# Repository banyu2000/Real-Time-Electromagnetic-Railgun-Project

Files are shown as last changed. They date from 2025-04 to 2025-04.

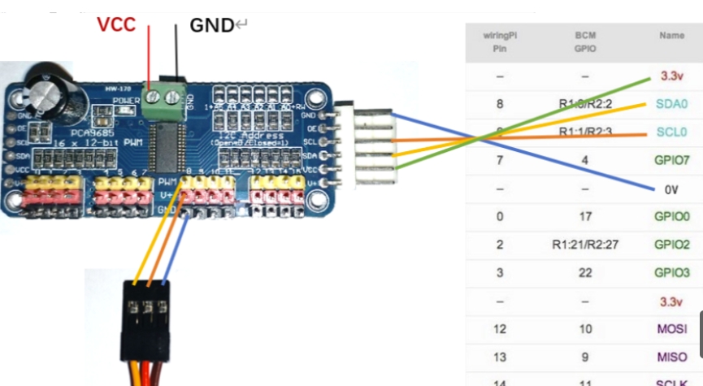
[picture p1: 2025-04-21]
docs/PCA9685_CONNECT_GUILDENCE.jpg

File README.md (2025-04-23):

# 🕊️ Real-Time Electromagnetic Railgun - Agricultural Deterrent System (Prototype)

This project is a real-time embedded system that detects visual targets (e.g. birds), calculates servo aiming, and triggers an actuator (electromagnetic railgun in demo).  
It is designed as a **proof-of-concept for smart deterrent systems**, particularly in agricultural environments.

## 🧩 System Overview

This project is organized into five tightly integrated subsystems, each responsible for a key piece of the “detect → aim → fire” feedback loop:

1. **Vision Module**  
   - Captures live video frames via libcamera  
   - Converts frames to OpenCV `cv::Mat` for processing  
   - Applies HSV color filtering + morphological operations to detect blue cylindrical targets  
   - Outputs the target’s centroid coordinates and contour bounding box

2. **Servo Control Module**  
   - Uses a PCA9685 I²C PWM driver to command two servos (horizontal & vertical)  
   - Converts detected error offsets (px) into angular adjustments (±0.5° precision)  
   - Supports two modes:  
     - **Manual Sweep**: continuous back‑and‑forth scan  
     - **Tracking**: lock onto detected target and hold position

3. **Launcher (Electromagnetic Barrel)**  
   - **Step‑up Circuit**: 3× 18650 cells → boost converter (15 µH coil + diode) → 1000 µF storage capacitor  
   - **Discharge Path**: relay (or N‑MOSFET) closes to dump capacitor into copper coil wound around a plastic barrel  
   - **Projectile**: small steel ball seated in the barrel’s center is launched by the magnetic pulse

4. **Callback & Multithreading Framework**  
   - **LibCam2OpenCV** runs camera capture in its own thread, invokes `hasFrame()` slot in the GUI thread  
   - **ServoThread** (inside `Window`) processes angle updates in a worker thread to keep UI responsive  
   - **SequenceController** runs charge–pause–discharge relay sequence on a detached thread when “lock” conditions are met  
   - Thread‐safe coordination via `std::atomic<bool>` and `std::function` callbacks

5. **Qt GUI Interface**  
   - **Live View**: displays current camera frame with overlaid detection box & center point  
   - **Controls**:  
     - **Start Sweep** button toggles manual scanning mode  
     - **Track Mode** button enables automatic target‐lock behavior  
   - **Indicators**: shows real‐time servo angles, relay status, and system health  
   - Built with Qt Widgets and optionally uses Qwt for custom gauges (e.g. QwtThermo)

---

All five subsystems are orchestrated by the main application, which:  
- Initializes hardware (I²C, GPIO, camera)  
- Launches the Qt event loop and camera capture  
- Monitors for SIGINT to gracefully shut down threads and reset actuators  
- Provides a modular codebase in `src/`, easy to extend with new sensors, actuators, or network interfaces  

---

##  Project Background & Motivation

In agriculture, birds cause significant damage to crops by eating seeds and fruits. Traditional scarecrow systems are passive, and manual patrols are time-consuming and ineffective.

Our project aims to address this problem by building an **automated deterrent platform**, capable of:
- Detecting moving visual targets using a camera
- Aiming servos to lock onto targets in real time
- Triggering an actuator (e.g., railgun / speaker / LED blaster) to deter targets

Although the current system uses a railgun for demonstration, the design is modular and can be adapted for:
-  Smart farm protection
-  Perimeter defense simulation
-  Embedded systems education

---

##  Demo Preview

>  Target detection + servo movement + firing sequence

Demo mp4

>  Real-time detection output

Detection Example

---

##  Tests Preview

Below are snapshots from our various unit- and integration‑tests, all located under the `tests/` directory:

| Test Module | Description | Preview |
|---|---|---|
| **Servo Test** | `tests/test1_servo/` sweep demo | Servo Test |
| **GUI Test** | `tests/test2_UI/` UI functionality | GUI Test |
| **IO Control Test** | `tests/test3_io_control/` relay logic | IO Test |
| **ServoCam Test** | `tests/test4_ServoCam/` full pipeline | ServoCam |
| **Camera Test** | `tests/test5_camera/` framerate check | Camera |

---

##  System Overview

-  **Vision Module**: HSV-based blue target detection (OpenCV)
-  **Servo Control**: Dual-axis aiming with PCA9685, ±0.5° accuracy
-  **Launcher**: Electromagnetic railgun with capacitor boost & relay control
-  **Callback & Multithreading**: Threads handle image capture, control logic, and GPIO actions
-  **Qt GUI**: Live video stream, system status, and manual controls

 Architecture diagram: [`docs/system_architecture.md`](docs/system_architecture.md)

---

##  How to Run

###  Build & Run Servo Test

```bash
mkdir build && cd build
cmake ..
make
sudo ./servo_test

``` 

---

###  Test Output 

- Servo sweeps automatically from 0° to 180°

- Vision module detects blue objects and overlays bounding boxes

- Qt UI displays live feedback and control panel

Full demo video : media/demo.mp4

---

###  Documentation (`/docs`)

| File | Description |
|---|---|
| [`project_log.md`](docs/project_log.md) | Project development timeline & milestones |
| [`system_architecture.md`](docs/system_architecture.md) | Hardware/software architecture |
| [`end_of_life.md`](docs/end_of_life.md) | Reflection, limitations & future improvements |
| [`credits.md`](docs/credits.md) | Team member responsibilities |

---

###  Repository Structure

- `build/` — Build output directory (excluded by `.gitignore`)
- `docs/` — Project documentation
  - `project_log.md` — Development timeline and milestones
  - `system_architecture.md` — Architecture and design overview
  - `end_of_life.md` — Final reflection and improvement analysis
  - `credits.md` — Team member responsibilities
- `media/` — Demo images, GIFs, and video assets
  - `demo.gif`, `vision_output.png`, `system_diagram.png`
- `src/` — Main source code (servo, vision, callback, GUI, etc.)
- `tests/` — Unit tests and module demos (e.g., `servo_test`)
- `.gitignore` — Git exclusion rules (build folders, binaries, temp files)
- `CMakeLists.txt` — CMake build configuration
- `LICENSE` — MIT open-source license
- `README.md` — Project overview, usage, and documentation links

---

###  Contributors

| Name | ID | Role |
|---|---|---|
| **Baichuan Shi**  | 2982811  | Servo control, GitHub management |
| **Xiang Chen** | 3052701  | IO logic, relay control |
| **Yu Ban** | 2931341  | Vision detection (OpenCV) |
| **Kunjin Chen** | 2981978  | Callback mechanism, threading |
| **Zhongkai Zhang**| 2969533  | Qt GUI development |
---

## 🎥 Social Media

Check out our project demo on TikTok:  
[Real‑Time Electromagnetic Railgun Demo](https://www.tiktok.com/@user99861255807300?_t=ZN-8ve2aKE0Rx0&_r=1)

---

##  Third‑Party Libraries

Project Name: libcamera2opencv  
Author: Bernd Porr  
Link: https://github.com/berndporr/libcamera2opencv  
License: GPL-2.0 License  

---

### License

This project is licensed under the MIT License. See LICENSE for details.

---

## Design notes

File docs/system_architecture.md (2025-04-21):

# System Architecture

This document describes the overall architecture of the Real-Time Electromagnetic Railgun System, including its functional modules, data/control flows, and hardware-software integration.

---

##  System Overview

The system consists of five tightly integrated subsystems:

| Subsystem | Description |
|---|---|
| **Vision Module** | Detects and tracks targets using a camera and OpenCV-based neural network |
| **Servo Control** | Adjusts the aiming angle based on target coordinates |
| **Firing Circuit** | Charges capacitors and releases high-current pulses via relay control |
| **I/O Control** | Reads and writes GPIO for relay switching and power status feedback |
| **UI Interface** | Provides real-time video feed and system status via a Qt GUI |

---

##  Module Interaction Flow

```plaintext
[Camera Feed] ─▶ [Vision Recognition] ─▶ [Callback Dispatch] ─▶ [Servo Control]
                                                     │
                                                     ▼
                                               [IO & Relay Trigger]
                                                     │
                                        [Capacitor Discharge (Fire)]
```

---
All components are coordinated via real-time callbacks and thread-safe communication queues.
---
## Hardware Block Diagram
## 🔌 Hardware Block Diagram

- **Power Supply**: 3× 18650 Li‑ion batteries in series (~12 V nominal)  
- **Step‑up Circuit**: Boost converter with 15 µH inductor + flyback diode  
  _(or use a commercial DC–DC boost module rated for ≥20 V, ≥5 A output)_  
- **Control Switches**:  
  - Prototype: manual toggles SW1/SW2  
  - Final: 2‑channel relay module driven by Raspberry Pi GPIO  
- **Capacitor**: 1000 µF electrolytic for energy storage before discharge  
- **Discharge Switch**: N‑MOSFET or relay to route discharge current into coil  
- **Barrel (Launcher Coil)**:  
  - Copper coil wound around a non‑conductive plastic tube  
  - Steel ball projectile seated in the tube’s center  
  - When discharged, the coil’s magnetic pulse propels the ball forward  

---

## Software Threading & Signal Handling
Thread / Task | Description
Vision Thread | Processes camera frames, outputs target positions
Callback Dispatcher | Routes vision output to servo + IO threads
Servo Thread | Converts target position to angle; sends to PCA9685
I/O Thread | Reads safety sensors, controls relay pins
UI Thread | Displays video stream, status indicators, user buttons
---

## Communication Interfaces
²C: Used for servo control via PCA9685 module

GPIO: Raspberry Pi controls relay signals (charge/discharge trigger)

Internal Queues: Thread-safe std::queue/Qt signals for module coordination

USB Camera or PiCamera: Frame source for real-time processing
---

## Notes on Electrical Design

Old Design (see schematic):

Uses MOSFET (VS-70TPS12PBF) for switching

Boost inductor + diode creates charging loop

Two push-button switches (SW1/SW2) manually control flow

New Design:

Replaces manual switches and MOSFET with relay modules

GPIO triggers allow safe, programmable operation

Enhanced with software interlock logic

---

## Summary

The system ensures:

Modular and testable architecture

Real-time control loop (detection → aiming → firing)

Safe hardware operation via callback and interlock logic

Clear power and control signal paths for easy debugging and reproduction

---

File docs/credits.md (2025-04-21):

# 👥 Project Team & Responsibilities

This document outlines the role and responsibilities of each team member in the **Real-Time Electromagnetic Railgun Project**, as well as the technical scope they covered.

---

## 🧑‍💻 Team Members & Detailed Contributions

### **🧭 Xiang Chen (3052701) – I/O Control & Switching Logic**

#### 🔹 Background
Develop I/O port drivers and control logic in `feature/io-control` to ensure stable hardware signal transmission.

#### 🔹 Responsibilities
- GPIO initialization via Linux subsystem
- Designed full port mapping table and pull-up/down setup
- Developed switch state machine (standby → ready → launch → reset)
- Implemented interlock + fault detection (short-circuit, voltage anomalies)
- Integrated I/O with servo and callback modules via thread-safe queues

#### ✅ Acceptance Criteria
- Signal delay ≤ 100μs, 100% I/O read/write accuracy
- Emergency stop triggered in ≤ 50ms
- Fully documented driver code

---

### **⚙️ Baichuan Shi (2982811) – Servo Control Module**

#### 🔹 Background
Servo control is key for adjusting the firing angle in the railgun. A stable, precise control system is required.

#### 🔹 Responsibilities
- Designed PID-based angle adjustment algorithm (±0.5° tolerance)
- Wrote custom servo driver via PCA9685
- Monitored real-time angle, speed, and errors
- Integrated control with vision and UI
- Conducted performance testing

#### ✅ Acceptance Criteria
- Angle error ≤ ±0.5°
- Fast target response, stable output
- Robust driver and feedback loop

---

### **🧠 Kunjin Chen (2981978) – Callback Coordination & Threading Architecture**

#### 🔹 Background
Ensure real-time concurrent processing between vision, servo, and I/O modules via efficient callback architecture.

#### 🔹 Responsibilities
- Designed C++ virtual interface / Qt signal-slot based callbacks
- Implemented asynchronous dispatching + exception handling
- Built multithreaded architecture using C++11 / QThreads
- Optimized for performance (e.g., lock-free queues, SIMD)
- Ensured memory safety with smart pointers

#### ✅ Acceptance Criteria
- Vision callback delay ≤ 100ms, servo delay ≤ 50ms
- CPU load ≤ 80% under stress
- ≥ 95% error handling coverage, ≤ 2s recovery time

---

### **📷 Yu Ban (2931341) – Vision Recognition**

#### 🔹 Background
Enhance the accuracy and efficiency of target detection in the `feature/vision-recognition` branch.

#### 🔹 Responsibilities
- Integrated and optimized YOLOv8-light for real-time detection
- Enhanced image pre-processing (noise filtering, white balance)
- Implemented DeepSORT-based multi-target tracking
- Packaged module as `libvision.so`, created API docs
- Achieved 80%+ unit test coverage

#### ✅ Acceptance Criteria
- mAP@0.5 ≥ 85%, inference time/frame ≤ 150ms
- Modular, documented, and testable code

---

### **🖥 Zhongkai Zhang (2969533) – Qt GUI Development**

#### 🔹 Background
Integrate live video and GPIO control into a smooth, functional Qt interface.

#### 🔹 Responsibilities
- Designed UI layout (video, controls, status monitor)
- Connected live PiCamera feed via OpenCV
- Implemented resolution settings, start/stop threading
- Built GPIO status widgets (e.g., QLEDWidget, error log)
- Created reusable Qt components with Doxygen docs

#### ✅ Acceptance Criteria
- Stream delay ≤ 500ms, UI buttons functional
- GPIO control latency ≤ 200ms
- Code passed PR review and Qt guidelines

---

## 🤝 Teamwork and Integration

- Followed GitFlow model with `feature/`, `develop`, and `release` branches
- Used GitHub Issues to manage tasks and document bugs
- Integrated via callback pipelines across vision ↔ servo ↔ IO
- Each member contributed test cases and documentation

---

## 🙏 Acknowledgements

This project was developed as part of **ENG5220: Real-Time Embedded Systems** at the University of Glasgow.

Special thanks to:

- **Prof. Bernd Porr** – for guidance on embedded control systems
- **Dr. Chongfeng Wei** – for support on hardware interfacing
- **All TAs and lab staff** – for test environment and debugging help

---

## 📜 License

Distributed under the [MIT License](../LICENSE).  
We welcome forks, feedback, and future contributions.

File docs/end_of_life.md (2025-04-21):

#  End of Life Analysis & Future Prospects

This document summarizes the current limitations, potential improvements, and reusable value of the Real-Time Electromagnetic Railgun Project. The system demonstrates a complete real-time feedback loop from vision-based target detection to servo-based aiming and electromagnetic firing. It is designed not only as a technical showcase, but also as a prototype to solve real-world control problems in security, automation, and education.

---

##  Real-Life Motivation

Many real-life scenarios such as smart defense systems, interactive shooting ranges, or embedded system education platforms require real-time decision-making based on visual input. Our system addresses this by combining:

- Visual detection of objects (color-based)
- Real-time servo aiming control
- Software-controlled electromagnetic actuation
- Integrated feedback via GUI

Applications include:

-  Smart deterrent systems (e.g. bird control in agriculture)
-  Interactive shooting/targeting training
-  Teaching platform for embedded systems and robotics

---

## Achievements Summary

- Servo angle control achieved with ±0.5° precision using PCA9685
- Real-time yellow object detection using OpenCV (HSV filtering + morphological operations)
- Detection latency under 50ms per frame (800×600 on Raspberry Pi 4)
- Multi-threaded callback architecture linking vision, control, and IO
- Integrated Qt GUI showing live video, detection bounding boxes, and system states
- Stable electromagnetic firing with software-defined state transitions

---

##  Known Limitations

| Category | Description |
|---|---|
| **Budget & Time** | Limited by academic constraints: low-cost camera impacts image clarity and detection robustness |
| **Hardware** | - Capacitor energy insufficient for rapid repeat fire<br>- Boost charging is slow<br>- Relay-based switching has delay and limited lifespan |
| **Mechanical Design** | No auto-reload mechanism; no environmental casing or protection |
| **Safety & Compliance** | System lacks industrial-grade protection (no watchdog, thermal cutoff, voltage monitoring) |

---

##  Future Improvements

- Replace relays with fast-switching IGBTs or power MOSFETs
- Use larger capacitors for better launch power and faster recharge
- Add auto-reloading mechanics and a secure protective casing
- Integrate thermal sensors, kill switches, and soft-fail mechanisms
- Upgrade to a better camera module or use Jetson Nano platform for high-speed image processing
- Modularize vision-to-servo link using lightweight messaging or ROS-lite interface

---

##  Reusability & Application Potential

This project can be repurposed or extended in multiple directions:

- **Agricultural automation**: Auto-targeting deterrents for wildlife control
- **Educational platform**: Demonstrates perception → decision → act loop for embedded systems teaching
- **Defense simulation**: Low-cost turret prototype for vision-guided robotics research

The modular nature and clean threading model make it suitable for forking and repurposing in future course projects or product prototypes.

---

##  Lessons Learned

- Git structure and branch discipline must be established early to avoid chaos later
- Physical circuits behave differently from simulation; real testing is essential at every stage
- Underestimating servo stall current and MOSFET load handling led to burnout and iteration delays
- Callback coordination and multithread safety should be prototyped early, not post-integration
- Continuous integration testing is more effective than final-phase testing rush

---

##  Conclusion

This project successfully demonstrates a reproducible real-time closed-loop embedded system capable of fulfilling real-world perception-to-action tasks. It also lays the foundation for further improvements in precision, safety, and intelligent control in small-scale robotic systems.

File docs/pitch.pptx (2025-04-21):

## Real Time Electromagnetic Railgun Project

01

Basic Functionality:

Automatically calculates launch velocity based on input angle and distance.

02

Advanced Features:

Utilizes visual recognition and laser ranging to determine barrel angle and target distance for automated projectile launching.

## Model demonstration

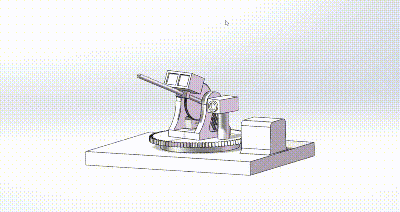
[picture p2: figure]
电磁炮[00h00m02s-00h00m19s]

System Components

Raspberry Pi Control System
Information Collection System
Human-Machine Interaction
System
Electromagnetic Railgun
System

Hardware Components

Raspberry Pi
Electromagnetic coil
High voltage capacitor bank
Boost module
Servo Motor
Laser Sensor
Vision Sensor
Power system (power supply)

banyu2000/Real-Time-Electromagnetic-Railgun-Project (https://github.com/banyu2000/Real-Time-Electromagnetic-Railgun-Project)

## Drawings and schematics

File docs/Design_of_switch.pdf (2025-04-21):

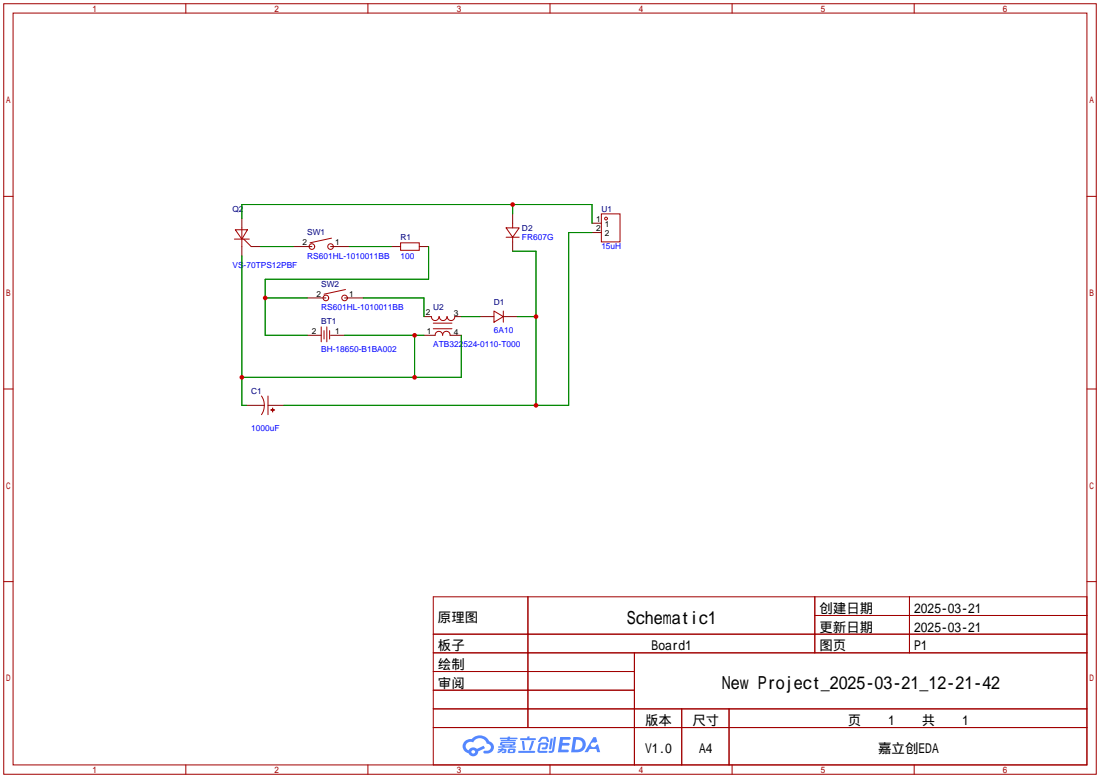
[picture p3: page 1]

原理图 | Schematic1 | 创建日期 | 2025-03-21

更新日期 | 2025-03-21

板子 | Board1 | 图页 | P1
绘制 | | New Project_2025-03-21_12-21-42
审阅

V1.0 | A4 | 嘉立创EDA

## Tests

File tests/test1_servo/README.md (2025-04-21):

# 🧪 Servo Unit Test – PCA9685 PWM Driver

This test verifies the functionality of the servo control system using a PCA9685 PWM driver over I2C on Raspberry Pi 5.

---

##  Purpose

This unit test:
- Initializes the PCA9685 device via I2C
- Continuously sweeps two servo motors across their full angular range (0° to 180°)
- Uses graceful termination (SIGINT) to reset both servos to 90° on exit

---

##  Files in this directory

| File | Description |
|---|---|
| `main.cpp` | Test program for dual-axis servo sweep |
| `PCA9685.cpp` | Implementation of the I2C PWM driver |
| `PCA9685.h` | Header file for PCA9685 class |
| `CMakeLists.txt` | CMake configuration for building the test |

---

##  Build Instructions

### Requirements:
- Raspberry Pi with I2C enabled (`/dev/i2c-1`)
- 2 servo motors connected to PCA9685 (channels 0 and 1)
- CMake & C++17 compiler (e.g., `g++`)

### Compile with CMake:
```bash
mkdir -p build && cd build
cmake ..
make
``` 
---

The output executable will be: servo_test

---

 ### Run the Test
```bash
sudo ./servo_test
``` 
The horizontal servo (channel 0) will sweep from 0° to 180°

The vertical servo (channel 1) will sweep from 180° to 0°

Press Ctrl+C to stop – the servos will return to 90° automatically

---

### Example console output:
```yaml
Horizontal: 0°   Vertical: 180°
Horizontal: 10°  Vertical: 170°
...
Program terminated. Servos reset.
```

---

### Test Outcome Criteria

Metric	Condition
I2C connection|	No runtime exception
Angle movement|	Smooth servo sweep observed
Exit handling|	Servos return to neutral

---

### Notes：

PCA9685 default I2C address: 0x40

If you're not using /dev/i2c-1, change I2C_DEV in PCA9685.h

Use a dedicated power supply for servos if they draw significant current

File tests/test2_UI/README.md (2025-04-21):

# 🧪 Qt UI Integration Test – Camera + GPIO Interface

This test verifies the functionality of the user interface using Qt5 on Raspberry Pi, with real-time camera integration and GPIO control layout preparation.

---

## ✅ Purpose

This integration update:
- Displays live camera feed from Raspberry Pi (libcamera or OpenCV)
- Constructs the main UI layout using Qt5
- Adds two interactive buttons at the bottom of the interface:
  - `Auto Shoot`
  - `Track Shoot`
- These buttons are now visible and placed for future GPIO interaction

---

## 📁 Files in this directory

| File | Description |
|---|---|
| `main.cpp` | Entry point of the Qt application |
| `window.cpp` | Implementation of the UI, image display, and layout |
| `window.h` | Header for the main Window class |
| `CMakeLists.txt` | CMake configuration for building the GUI |

---

## 🔧 Build Instructions

### Requirements:
- Raspberry Pi with Qt5 and OpenCV installed
- Camera module (e.g., Raspberry Pi Camera v1.3) connected via CSI
- CMake, g++, and pkg-config available

### Compile with CMake:
```bash
mkdir -p build && cd build
cmake ..
make

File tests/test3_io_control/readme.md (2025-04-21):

#  Relay Switch Unit Test – GPIO Control with libgpiod

This unit test verifies GPIO-based relay switching using the `libgpiod` C++ library on Raspberry Pi 5.  
It simulates a charge–discharge sequence using two GPIO pins controlling physical switches.

---

##  Purpose

This test program:
- Initializes two GPIO output lines (GPIO27 and GPIO22)
- Responds to user input (`on`) to activate a switch sequence
- Gracefully shuts down and resets the switches on `Ctrl+C` or `exit` command

---

##  Files in This Directory

| File | Description |
|---|---|
| `main.cpp` | Main test program with GPIO sequence control  |
| `CMakeLists.txt` | Add if using CMake to build the program |

---

##  Build Instructions

### Prerequisites:
- Raspberry Pi 5 with GPIO support
- Relay or LED circuit connected to GPIO27 and GPIO22
- `libgpiod` installed:
  ```bash
  sudo apt install libgpiod-dev
  ```
  
---

## Compile Manually:
```bash
mkdir build && cd build
cmake ..
make
```
---

## Run the Test
```bash
 ./relay_test
```
---

### You will see a prompt like:
```scss
System ready. GPIO27(switch1), GPIO22(switch2)
> 
```
Type on to trigger the switch sequence:

switch1 turns ON for 2s → OFF

0.5s pause

switch2 turns ON for 1s → OFF

Type exit or press Ctrl+C to quit. All GPIOs will be turned off cleanly.

---

## Test Outcome Criteria

Metric | Condition
GPIO Initialization | No runtime exception or access error
Sequence Logic | Relays trigger in correct timing
Signal Handling | Exits cleanly on Ctrl+C, resets pins

---

### Notes

-Uses GPIO27 and GPIO22 by default. Change in SequenceController if needed.

-Requires libgpiod and root privileges (sudo) to access GPIO.

-You can connect relays or LEDs for visual confirmation.

---

## Example Output
```YAML
System ready. GPIO27(switch1), GPIO22(switch2)
> on
Switch ON
Switch OFF
Switch ON
Switch OFF
> exit
System shutdown
```
---

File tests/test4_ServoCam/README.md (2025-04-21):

# ServoCam Test

A real-time object detection and tracking system that integrates **libcamera**, **OpenCV**, and a **PCA9685** PWM servo driver, featuring a Qt-based GUI with auto-scan and tracking modes.

---

## Features

- **Camera Capture**: High-performance image acquisition using **libcamera** and **OpenCV**
- **Object Detection**: Yellow cylindrical can detection via HSV color filtering and contour analysis
- **Servo Control**: Pan-tilt control of two servos through PCA9685 over I²C
- **Tracking Mode**: Real-time target centering by adjusting servo angles based on object position
- **Scan Mode**: Automatic sweeping movement when no target is detected
- **Multithreading**: Dedicated `ServoThread` for servo operations; main thread handles image processing and UI
- **Callback Mechanism**: `Libcam2OpenCV` invokes a callback for each captured frame
- **GUI Interface**: Built with Qt5 Widgets and Qwt thermometer widget to display video feed and system status

---

## Repository Structure

```
├── CMakeLists.txt       # Build configuration
├── main.cpp             # Application entry point, initializes Qt application and main window
├── window.h/.cpp        # Qt window: UI setup, image updates, detection logic, and servo control
├── libcam2opencv.h/.cpp # Wrapper for libcamera to deliver OpenCV Mat frames via callback
├── PCA9685.h/.cpp       # PCA9685 I²C driver implementation and angle-to-PWM mapping
└── README.md            # Project documentation (this file)
```

---

## Hardware Requirements

- A libcamera-supported camera module (e.g., Raspberry Pi Camera)
- PCA9685 PWM driver connected via I²C
- Two standard analog servos connected to PCA9685 channels 0 (pan) and 1 (tilt)
- Linux-based embedded platform (e.g., Raspberry Pi) with I²C enabled (`/dev/i2c-1`)

---

## Software Dependencies

- **C++17**
- **libcamera**
- **OpenCV**
- **Qt5 Widgets**
- **Qwt**
- **pthreads**
- **pkg-config**

---

## Build and Run Instructions

1. **Install Dependencies** (Debian/Ubuntu):
   ```bash
   sudo apt update
   sudo apt install -y libopencv-dev libqt5widgets5 libqt5core5 pkg-config libqwt-qt5-dev libcamera-dev
   ```

2. **Build the Project**:
   ```bash
   mkdir -p build && cd build
   cmake ..
   make -j$(nproc)
   ```

3. **Run the Application**:
   ```bash
   sudo ./ServoCam
   ```
   (*sudo* may be required for I²C access)

---

## Usage

- **Start Servo**: Click to begin or stop automatic scanning.
- **Track Mode**: Toggle to enable or disable object tracking. In tracking mode, the servos will follow the detected can; if no can is found, the system reverts to scan mode.

---

## Module Overview

### libcam2opencv

- Initializes and configures the camera via **libcamera**.
- Maps camera buffers into **OpenCV** `cv::Mat` frames.
- Emits each frame through a virtual callback `hasFrame(const cv::Mat&, const libcamera::ControlList&)`.
- Allows setting capture parameters: resolution, framerate, brightness, contrast.

### PCA9685

- Opens `/dev/i2c-1` and sets up the PWM driver at 50 Hz.
- Provides `setAngle(uint8_t channel, float angle)` to convert angles (0–180°) into PWM pulse widths.
- Handles raw register writes and frequency adjustment.

### Window (Qt GUI)

- Builds the user interface with Qt5 Widgets and a Qwt thermometer for status display.
- Receives each frame in `updateImage()`, applies detection, draws overlays, and updates the video display.
- Contains `ServoThread` for continuous scanning movements and invokes servo adjustments in tracking mode.

---

## Customization

- Modify HSV threshold values in `detectCans()` to detect objects of different colors.
- Adjust pan/tilt step sizes for faster or smoother tracking responses.
- Replace the HSV-based detector with machine learning models (e.g., YOLO, TensorFlow) for advanced object recognition.

---

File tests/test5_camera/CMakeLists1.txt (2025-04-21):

cmake_minimum_required(VERSION 3.6)

if(NOT CMAKE_BUILD_TYPE AND NOT CMAKE_CONFIGURATION_TYPES)
  set(CMAKE_BUILD_TYPE "RelWithDebInfo")
endif()

project(CamViewer
	DESCRIPTION "Example QT application which displays the camera image"
	LANGUAGES CXX)

set (CMAKE_CXX_STANDARD 17)

set (CMAKE_CXX_FLAGS "-Wall -Winvalid-pch -Wnon-virtual-dtor -Wextra -Wno-unused-parameter")

find_package(PkgConfig)

find_package(OpenCV REQUIRED)

find_package(Qt5 COMPONENTS Widgets REQUIRED)

set(CMAKE_AUTOMOC ON)
set(CMAKE_AUTORCC ON)
set(CMAKE_AUTOUIC ON)

pkg_check_modules(LIBCAMERA REQUIRED IMPORTED_TARGET libcamera)
message(STATUS "libcamera library found:")
message(STATUS "    version: ${LIBCAMERA_VERSION}")
message(STATUS "    libraries: ${LIBCAMERA_LINK_LIBRARIES}")
message(STATUS "    include path: ${LIBCAMERA_INCLUDE_DIRS}")

message(STATUS "opencv:")
message(STATUS "    version: ${OpenCV_VERSION}")
message(STATUS "    include path: ${OpenCV_INCLUDE_DIRS}")

include_directories(${CMAKE_SOURCE_DIR} ${LIBCAMERA_INCLUDE_DIRS} ${OPENCV_INCLUDE_DIRS})
include(GNUInstallDirs)

add_executable(qtviewer
  window.cpp
  main1.cpp
)

target_link_libraries(qtviewer PkgConfig::LIBCAMERA)
target_link_libraries(qtviewer Qt5::Widgets)
target_link_libraries(qtviewer qwt-qt5)
target_link_libraries(qtviewer ${OpenCV_LIBS})
target_link_libraries(qtviewer cam2opencv)

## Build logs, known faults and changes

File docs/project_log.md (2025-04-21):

# 📅 Project Development Log

This document records key milestones and development progress of the Real-Time Electromagnetic Railgun Project.

---

##  Log Format

| Date | Task / Milestone | Description / Outcome | Responsible |
|---|---|---|---|

| **Feb 5**  |  Pitch Day                                      | Initial team formation and concept pitching                | All members |
| **Feb 26** |  Hardware Prepared                              | All critical components (servo, PCA9685, camera, relays) purchased | All members |
| **Mar 5**  |  Soldering Manual Switch Circuit                | Physical switch-based charging/discharging circuit completed | All members |
| **Mar 12** |  Successful Physical Firing Test                | Manual trigger circuit connected to railgun, projectile launched successfully without Raspberry Pi | All members |
| **Mar 19** |  Knowledge Allocation & Research Begins         | Team divided into respective development areas (vision, IO, GUI, servo, callback) | All members |
| **Apr 10** |  Servo Module Functional                        | Dual-axis servo control tested using PCA9685 driver         | Baichuan Shi |
| **Apr 13** |  Vision Module Working                         | Object detection module (YOLO) tested successfully           | Yu Ban |
| **Apr 15** |  GUI Operational                                | Qt interface setup with video stream and control panels      | Zhongkai Zhang |
| **Apr 16** |  GitHub Structure Optimization Started          | Repo structure, commits, and branches reviewed and re-organized | Baichuan Shi |
| **Apr 17** |  MOSFET Burnout Identified & Analyzed          | During testing, charging transistor blew due to overcurrent; cause diagnosed and relay replacement proposed | Reported by Baichuan Shi, followed up by Xiang Chen |
| **Apr 18** |  Callback Function Integration                  | Callback mechanism and multi-threaded control logic successfully integrated between vision, servo, and IO | Kunjin Chen |
| **Apr 19** |  Relay Control Circuit Integrated               | Relay-based switching tested and confirmed operational       | Xiang Chen |
| **Apr 20** |  Final Version Released                         | Code and hardware integration completed, system runs stably | All members |

---

##  Notes

- Major testing milestones were recorded with video or physical measurement evidence.
- All code components were developed and pushed under `feature/` branches, then integrated via `develop`.

---

## 📜 License & Credits

This log is part of the documentation for the Real-Time Electromagnetic Railgun Project under [MIT License](../LICENSE).

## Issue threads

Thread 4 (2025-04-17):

Issue #1: Qt UI Development & Hardware Integration (Assignee: Zhongkai Zhang)

BOB12600, 2025-04-17:
###  Background
In the electromagnetic railgun project, it is necessary to integrate the **camera video stream** and **GPIO control signals** into the **Qt interface** to achieve visual operation and status monitoring. The UI should be smooth and reasonably laid out.

###  Task Overview
#### 1. UI Basic Framework Setup
- Define the structure of the **MainWindow**: video display area, control button area, and status monitoring panel.
- Use `QVBoxLayout` / `QHBoxLayout` for a **responsive layout** adaptable to different resolutions.
- Set window title, icon, and menu bar.

#### 2. Camera Video Stream Integration
- Use OpenCV to connect to the **camera driver**.
- Create a `QVideoWidget` to display real-time video.
- Implement **start/stop controls** and resolution settings.
- Use **multi-threading** to prevent UI freezing.

#### 3. GPIO Interface Status Display
- Read GPIO port status (e.g., **servo angle**, **coil voltage**) and display via `QLEDWidget` / `QLabel`.
- Implement interaction logic between `QPushButton` and GPIO for manual control.
- Add **UI alarm prompts** (e.g., red highlight, error log) for exceptions.

#### 4. Component Definition & Code Specification
- Create reusable custom components per Qt component-based design.
- Maintain **≥80% code comment rate** and use **Doxygen format** for key logic.
- Ensure compatibility with `feature/vision-recognition` and `feature/servo-control`.

###  Acceptance Criteria
- UI layout matches design prototype, buttons function normally.
- Camera stream delay ≤ **500ms**.
- GPIO status updates match hardware, control response time ≤ **200ms**.
- Code passes PR review and follows Qt standards.

Discoverer626, 2025-04-18:
**GUI Development Progress Report**

**Module:** GUI Interface (`feature/gui`)
**Status:** In Progress

---

### Overview

This report outlines the current progress of the **Graphical User Interface (GUI)** for the railgun control system. The focus is on building a user-friendly and functional interface using **Qt**, with real-time integration of control elements and live camera feed. The initial framework has been implemented in `mainwindow.cpp`, and key user interactions are in place.

---

### Current Progress

#### ✅ Main Window Construction

- Created a main window using `QMainWindow`, with a vertical layout.
- Set up full-screen or maximized window behavior for deployment on Raspberry Pi.
- Basic styling and widget spacing applied for clear layout.

#### ✅ Button Functionality

- Added two core buttons:
  - `Auto Shoot` – for fixed-angle firing.
  - `Track Shoot` – for vision-guided firing logic.
- Connected both buttons to placeholder slot functions using Qt signal-slot mechanism.

#### ✅ Camera Feed Display

- Integrated OpenCV with Qt to capture live camera frames.
- Converted `cv::Mat` to `QImage` and displayed it using `QLabel`.
- Implemented periodic frame updates via `QTimer` for real-time display.

---

### Next Steps

#### 🔄 GPIO Integration

- Connect button actions to actual GPIO output control.
- Interface with `FireControl` class to trigger firing pins via WiringPi.

#### 🔄 Servo Control

- Call `PCA9685Driver` from button handlers to control horizontal/vertical servos.
- Use preset angles (Auto Shoot) and dynamic input (Track Shoot).

#### 🔄 Modular Refactor (Optional)

- Separate GUI logic and hardware interface logic for better maintainability.
- Use custom Qt widgets for camera, control panel, and status display.

---

*Author: @Discoverer626 *
*Updated: Apr 18, 2025*
``

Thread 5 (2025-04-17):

**Core Callback Function Development and Multithreading Optimization (Vision/Servo Control)**

BOB12600, 2025-04-17:
###  Background
To ensure **real-time concurrent processing**, implement **high-performance callback logic** in the vision and servo branches.

###  Task Overview
#### 1. Vision Recognition Callback Optimization
- Design callback interface (e.g., C++ virtual functions / Qt signals).
- Add **asynchronous handling** to prevent queue backlog.
- Use `try-catch` to handle exceptions and log errors.

#### 2. Servo Control Callback
- Convert target data to **servo angle parameters**.
- Coordinate **multi-servo control** (pitch + horizontal).
- Handle hardware errors (e.g., timeout, limit switch) and reset.

#### 3. Multithreading Architecture
- Create threads via `QThread` / C++11 to handle:
  - Vision recognition
  - Callback logic
  - IO communication
- Use mutexes / lock-free queues to ensure **thread safety**.

#### 4. Optimization & Refactoring
- Profile and optimize callback performance (e.g., use SIMD).
- Maintain **cyclomatic complexity ≤ 15**.
- Use **C++17 features** (e.g., `std::shared_ptr`), ensure memory safety.

###  Acceptance Criteria
- Vision callback delay ≤ **100ms**, servo response time ≤ **50ms**.
- CPU usage ≤ **80%** under full load.
- Error handling coverage ≥ **95%**, recovery time ≤ **2s**.
- No memory leak warnings from static analysis tools.

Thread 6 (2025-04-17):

I/O Port Deployment and Switch Control Program Development

BOB12600, 2025-04-17:
###  Background
Develop **I/O port drivers** and **control logic** in `feature/io-control` to ensure stable hardware signal transmission.

###  Task Overview
#### 1. Port Initialization
- Write drivers using **Linux GPIO subsystem**.
- Create a **port mapping table** (pin number, function).
- Set default levels and pull-up/down states on boot.

#### 2. Switch Control Logic
- Design a **state machine**: standby → ready → launch → reset.
- Implement **interlock mechanism** (e.g., check safety sensors).
- Add fault detection (e.g., short-circuit, voltage anomalies) with emergency stop.

#### 3. Module Integration
- Provide GPIO status query interfaces.
- Define instruction protocols with `feature/servo-control` and `feature/callback-compliance-coordination`.
- Use **thread-safe queues** (e.g., `std::queue`) for data transmission.

###  Acceptance Criteria
- I/O read-write accuracy: **100%**, signal delay ≤ **100μs**.
- Switch logic transitions smoothly, interlock effective.
- Fault detection ≥ **90%**, emergency stop ≤ **50ms**.
- Code is well-commented and follows driver dev standards.

Roger-chen-push, 2025-04-18:
**# MOSFET Control Process and Program Implementation**

---

**## MOSFET Selection**
Select MOSFETs with high voltage and current tolerance. In this design, the STP36NF06L MOSFET model is selected for use.

---

**## GPIO Initialization**
1. Added voltage level check logic to ensure compliance with MOSFET gate drive voltage requirements (3.3V).
2. Pin allocation:
   - Energy storage control: GPIO17 (BCM coding, physical pin 11)
   - Firing control: GPIO27 (BCM coding, physical pin 13)
3. Drive signal optimization:
   - A 120Ω resistor is connected in series between the GPIO and the MOSFET gate to limit gate charging current.

---

**## Switch Control Functions**
1. Wrote `enableStorage()` and `triggerFire()` functions to control MOSFET switching status via the `gpiod` library.
2. Added a safety delay (50ms) between switching actions to prevent transient current surges from damaging components.

---

**## Testing Process**
1. **Energy Storage Phase**:
   MOSFET 1 is turned ON, and the capacitor bank is charged to the target voltage via the power supply (requires an external voltage detection module).
2. **Firing Phase**:
   After MOSFET 1 is turned OFF, MOSFET 2 is momentarily turned ON to discharge the capacitor's energy through the coil, generating a strong magnetic field to propel the projectile.

---

**## Next Steps**
1. Integrate capacitor charging feedback signals with timing control synchronization.
2. Develop a command-line/graphical interface for manual control and parameter adjustment.
3. Conduct high-current stress testing using actual electromagnetic coils.

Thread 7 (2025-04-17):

Visual Recognition Algorithm Optimization

BOB12600, 2025-04-17:
###  Background
Enhance the accuracy and efficiency of **target detection** in the `feature/vision-recognition` branch.

###  Task Overview
#### 1. Model Optimization
- Refactor model (e.g., **YOLOv8-light**) to boost speed by **30%**.
- Enhance image pre-processing (white balance, noise filtering).
- Implement **multi-target tracking** (e.g., DeepSORT) for ≥5 targets.

#### 2. Modularity & Maintainability
- Package as `libvision.so`, provide clear API docs.
- Add **JSON-based parameter serialization**.
- Ensure ≥ **80% unit test coverage**, including edge cases.

###  Acceptance Criteria
- mAP@0.5 ≥ **85%**, inference time/frame ≤ **150ms** (Jetson Nano).
- High modularity, clear dependencies, cross-platform build supported.

banyu2000, 2025-04-18:
**Vision Module Development Progress Report**
**Module: Object Detection \& Tracking (feature/vision-tracking)**
**Status: In Progress**

---

### **Overview**

This update summarizes the current progress of the vision module, which focuses on real-time detection and tracking of yellow cans using OpenCV and Qt. The module integrates camera input, image processing, and GUI display to provide visual feedback for servo control integration.

---

### **Window Class Implementation**

#### **Core Functionality**

1. **Camera Initialization**
    - Successfully initialized the `Libcam2OpenCV` camera interface.
    - Implemented frame callback (`MyCallback`) to process video streams.
2. **Image Processing Pipeline (`detectCans`)**
    - **Color Space Conversion**: Converted BGR frames to HSV for robust color segmentation.
    - **Yellow Mask Generation**: Applied HSV thresholds (`Scalar(15, 120, 80)` to `Scalar(30, 255, 255)`) to isolate yellow regions.
    - **Morphological Operations**:
        - Performed closing (`MORPH_CLOSE`) to fill gaps.
        - Applied opening (`MORPH_OPEN`) to eliminate noise.
    - **Contour Detection \& Filtering**:
        - Extracted external contours using `findContours`.
        - Filtered candidates based on aspect ratio (0.5–0.7) and area.
        - Implemented a scoring system combining area and aspect ratio similarity for optimal selection.
    - **Visualization**:
        - Drew bounding boxes (yellow) and center points (blue) on detected cans.
3. **GUI Integration (`updateImage`)**
    - Displayed processed frames in a `QLabel` with RGB conversion.
    - Integrated `QwtThermo` to visualize brightness at the image center.

---

### **Main.cpp Test Example**

- **Functionality**:
    - Continuously captures frames and updates the GUI in real time.
    - Displays brightness values dynamically via the thermo widget.
- **Performance**:
    - Achieved stable frame rates (tested at 30 FPS on Raspberry Pi 4).
    - Demonstrated robust detection under varying lighting conditions.

---

### **Integration Readiness**

- **Callback Compatibility**: The `updateImage` method is structured to feed detected can coordinates (center point) to external modules (e.g., servo control).
- **Data Output**: Current implementation provides `best_rect` (bounding box) and center coordinates for potential servo targeting.

---

### **Next Steps**

1. **Coordinate Mapping**:
    - Convert pixel coordinates to servo angles for real-time tracking.
2. **Integration with Servo Control**:
    - Trigger `setAngle` calls in `MyCallback` based on detected can positions.
3. **Optimization**:
    - Reduce latency by decoupling image processing and GUI updates.
    - Implement multi-threading for improved performance.
4. **Validation**:
    - Conduct edge-case testing (e.g., overlapping cans, low-contrast backgrounds).
    - Add unit tests for contour scoring logic and morphological operations.

---

**Note**: The vision module is currently functional for standalone detection. Pending servo integration and performance tuning will complete the closed-loop tracking system.

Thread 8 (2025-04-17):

Servo Control System Development

BOB12600, 2025-04-17:
###  Background
Servo control is key for adjusting the firing angle in the railgun. A **stable, precise control system** is required.

###  Task Overview
#### 1. Control Algorithm
- Design angle adjustment algorithm based on **vision input**.
- Use **PID control** to limit angle error to **±0.5°**.

#### 2. Hardware Driver
- Write servo driver to enable **accurate command execution**.
- Monitor real-time status: angle, speed, etc.

#### 3. Integration & Testing
- Integrate with **vision** and **UI** modules.
- Perform system-wide **functional, performance, and stability testing**.

###  Acceptance Criteria
- Servo angle error ≤ **±0.5°**, fast response to targets.
- Reliable driver, accurate monitoring data.
- Integrated system runs stably without major faults.

BOB12600, 2025-04-18:
##  Servo Control Development Progress Report

**Module:** Servo Control (`feature/servo-control`)
**Status:** In Progress

---

###  Overview
This update covers the current progress of the **servo control system**, focusing on the implementation of the `PCA9685` class and the corresponding example in `main.cpp`. The goal is to enable precise servo control through I2C communication with the PCA9685 device.

---

###  PCA9685 Class Implementation

####  Constructor
- Successfully opened the I2C device.
- Set the correct I2C address for the PCA9685.
- Performed a **reset operation**.
- Set the **PWM frequency** to the default value of **50Hz**.

####  `writeReg` Method
- Writes data to a **specific register** of the PCA9685.

####  `reset` Method
- Resets the **MODE1 register** of the PCA9685 to ensure a clean state.

####  `setPWMFreq` Method
- Sets the **PWM frequency** based on input.
- Automatically limits the frequency to a **reasonable range**.

####  `setPWM` Method
- Sets the **start and end times** of the PWM signal for a specific channel.

####  `setAngle` Method
- Converts a given **angle value** to a **PWM pulse**.
- Calls `setPWM()` internally to rotate the servo to the desired angle.

---

###  `main.cpp` Test Example

####  Functionality
- Continuously adjusts the **horizontal** and **vertical** servo angles in a loop.
- Adds a **1-second delay** after each adjustment using `sleep(1)`.

####  Signal Handling
- Implements `signalHandler()` to catch the **SIGINT** signal (`Ctrl+C`).
- When triggered, both servos are **reset to 90°** as a default neutral position.

---

###  Next Steps
- Integrate with **vision recognition callback** module.
- Add **PID control** for smoother motion.
- Complete unit testing and validation across edge cases.

---

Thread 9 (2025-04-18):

P36NF06L MOSFET Breakdown Due to High Inrush Current — Resolved with Relay Replacement

BOB12600, 2025-04-18:
### Description:
During testing of the boost/buck circuit, the P36NF06L MOSFET originally used to control capacitor charging failed catastrophically. Power was supplied by three 18650 lithium batteries in series (~11.1–12V). Upon engaging the charging path, the MOSFET sparked and was permanently damaged.

### Component & Circuit Info:
- **MOSFET Model**: P36NF06L (N-channel Power MOSFET)
- **Power Supply**: 3 x 18650 cells in series (~11.1–12V)
- **Function**: Switching element for capacitor charging
- **Failure Mode**: Sparking upon activation, complete breakdown
- **Location in Circuit**: Left-side MOSFET in the schematic

### Cause Analysis:
The applied voltage was well within the MOSFET's rated 60V drain-source breakdown limit. However, due to the near-short-circuit behavior of the capacitor during initial charging, the MOSFET experienced an excessive **inrush current**, likely exceeding its 30A continuous or even 120A pulsed current rating. This caused **current-induced breakdown**.

### Fix Implemented:
To mitigate the issue, the damaged MOSFET has been **replaced with a relay** that has a higher current tolerance. Relays are better suited for handling high current surges due to their mechanical contact design.

### Follow-up Recommendations:
- Perform endurance and current stress testing on the new relay-based switching circuit.
- Consider adding a current-limiting resistor or soft-start control in the capacitor charging path.
- Update schematics and documentation to reflect the hardware change and fix implementation.

### Reflection:
This incident demonstrates the risk of relying solely on MOSFETs without current protection in high-surge applications. In future designs involving capacitor charging or inductive loads, component current limits should be carefully evaluated, and protective strategies should be implemented early in the design process.

Roger-chen-push, 2025-04-20:
###  Issue Update: P36NF06L MOSFET Breakdown Due to High Inrush Current

We have analyzed the failure of the P36NF06L N-channel MOSFET that occurred during physical switch testing (bypassing Raspberry Pi control). The issue was caused by excessive **inrush current during capacitor charging**, which exceeded the rated pulsed drain current (IDM) of the component.

###  Root Cause

- Battery configuration: 3× 18650 Li-ion cells (approx. 11.1–12.6V total)
- Capacitor charged directly through the MOSFET, resulting in a large surge current
- The P36NF06L (rated for 30A continuous, 120A pulse) failed due to thermal stress or avalanche breakdown
- Failure symptoms: visible spark, component burnout, and loss of gate control

###  Solution Implemented

- **Replaced MOSFETs with two relays** (independent for charge/discharge control)
- Physical switch circuit now avoids high-speed switching components, reducing EMI and thermal stress
- Tested and validated: relay-controlled charge/discharge path works as expected
- Relay delay and lifespan are acceptable for current test purposes

###  Lessons Learned

- Capacitor charging should always consider surge current protection (e.g., soft-start, series resistance)
- Relays, while slower, provide robust isolation for low-frequency switching
- Future iterations may use IGBT + soft-start logic for faster and safer discharge paths

---

Status: **Resolved**

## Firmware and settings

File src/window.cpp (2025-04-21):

// window.cpp
#include "window.h"
#include <opencv2/opencv.hpp>
#include <QMessageBox>
#include <thread>       
#include <chrono>      

using namespace std::chrono_literals; 

SequenceController::SequenceController() 
    : chip_("gpiochip0"), 
      line1_(chip_.get_line(27)),
      line2_(chip_.get_line(22)) 
{
    line1_.request({"switch1", gpiod::line_request::DIRECTION_OUTPUT, 0}, 1);
    line2_.request({"switch2", gpiod::line_request::DIRECTION_OUTPUT, 0}, 1);
}

// SequenceController  start_sequence 
void SequenceController::start_sequence() {
    if (running_) return;
    running_ = true;
    
    std::thread([this]() {
        control_switch(line1_, 3000);
        std::this_thread::sleep_for(500ms); // 500ms 
        control_switch(line2_, 1000);
        running_ = false;
    }).detach();
}

void SequenceController::stop() {
    line1_.set_value(1);
    line2_.set_value(1);
}

// control_switch 
void SequenceController::control_switch(gpiod::line& line, int duration_ms) {
    line.set_value(0);
    std::this_thread::sleep_for(std::chrono::milliseconds(duration_ms)); //
    line.set_value(1);
}

Window::Window(QWidget *parent) : QWidget(parent) {
    setupUI();
    try {
        servoDriver = new PCA9685();
        servoThread = new ServoThread(servoDriver, &servoMutex);
        connect(servoThread, &ServoThread::servoError, this, &Window::handleServoError);
        gpioController = std::make_unique<SequenceController>();
    } catch (const std::exception& e) {
        QMessageBox::critical(this, "Initialization Error", e.what());
    }

    myCallback.window = this;
    camera.registerCallback(&myCallback);
    camera.start();
}

Window::~Window() {
    camera.stop();
    servoThread->stop();
    servoThread->wait();
    delete servoThread;
    delete servoDriver;
    if (gpioController) gpioController->stop();
}

void Window::setupUI() {
    thermo = new QwtThermo;
    thermo->setFillBrush(QBrush(Qt::red));
    thermo->setScale(0, 255);
    
    image = new QLabel;
    QHBoxLayout *hLayout = new QHBoxLayout;
    hLayout->addWidget(thermo);
    hLayout->addWidget(image);

    autoShootBtn = new QPushButton("Start Servo");
    trackShootBtn = new QPushButton("Track Mode");
    connect(autoShootBtn, &QPushButton::clicked, this, &Window::onAutoShoot);
    connect(trackShootBtn, &QPushButton::clicked, this, &Window::onTrackShoot);

    QHBoxLayout *btnLayout = new QHBoxLayout;
    btnLayout->addWidget(autoShootBtn);
    btnLayout->addWidget(trackShootBtn);

    QVBoxLayout *mainLayout = new QVBoxLayout(this);
    mainLayout->addLayout(hLayout);
    mainLayout->addLayout(btnLayout);
}

void Window::onAutoShoot() {
    if (!servoThread->isRunning()) {
        servoThread->start();
        autoShootBtn->setText("Stop Servo");
    } else {
        servoThread->stop();
        autoShootBtn->setText("Start Servo");
    }
}

void Window::onTrackShoot() {
    trackingEnabled = !trackingEnabled;
    trackShootBtn->setText(trackingEnabled ? "Disable Track" : "Track Mode");
    if(trackingEnabled) {
        m_currentPan = 90;
        m_currentTilt = 90;
        m_scanDirection = 1;
    }
}

void Window::calculateServoAngles(const cv::Point &target, const cv::Size &frameSize) {
    const cv::Point frameCenter(frameSize.width/2, frameSize.height/2);
    float xOffset = (target.x - frameCenter.x) / (float)frameCenter.x;
    float yOffset = (target.y - frameCenter.y) / (float)frameCenter.y;

    const float panStep = 0.3f;
    const float tiltStep = 0.2f;

    float newPan = m_currentPan + xOffset * panStep;
    float newTilt = m_currentTilt + yOffset * tiltStep;

    newPan = qBound(20.0f, newPan, 160.0f);
    newTilt = qBound(90.0f, newTilt, 135.0f);

    QMutexLocker locker(&servoMutex);
    servoDriver->setAngle(0, newPan);
    servoDriver->setAngle(1, newTilt);
    m_currentPan = newPan;
    m_currentTilt = newTilt;
}

void Window::scanningMovement() {
    QMutexLocker locker(&servoMutex);
    
    m_currentPan += 2 * m_scanDirection;
    if(m_currentPan >= 180 || m_currentPan <= 0) {
        m_scanDirection *= -1;
        m_currentTilt = qBound(90.0f, m_currentTilt + 5.0f, 135.0f);
        if(m_currentTilt >= 135) m_currentTilt = 90;
    }
    
    servoDriver->setAngle(0, m_currentPan);
    servoDriver->setAngle(1, m_currentTilt);
}

void Window::detectCans(cv::Mat &frame) {
    cv::flip(frame, frame, 0);

    cv::Mat hsv;
    cv::cvtColor(frame, hsv, cv::COLOR_BGR2HSV);

    cv::Scalar lower_yellow(15, 120, 80);
    cv::Scalar upper_yellow(30, 255, 255);
    cv::Mat yellow_mask;
    cv::inRange(hsv, lower_yellow, upper_yellow, yellow_mask);

    cv::Mat kernel = cv::getStructuringElement(cv::MORPH_ELLIPSE, cv::Size(7,7));
    cv::morphologyEx(yellow_mask, yellow_mask, cv::MORPH_CLOSE, kernel);
    cv::morphologyEx(yellow_mask, yellow_mask, cv::MORPH_OPEN, kernel);

    std::vector<std::vector<cv::Point>> contours;
    cv::findContours(yellow_mask, contours, cv::RETR_EXTERNAL, cv::CHAIN_APPROX_SIMPLE);

    cv::Rect best_rect;
    double max_score = 0.0;

    for (const auto &contour : contours) {
        cv::Rect rect = cv::boundingRect(contour);
        double aspect_ratio = (double)rect.width / rect.height;
        bool aspect_valid = (aspect_ratio > 0.5 && aspect_ratio < 0.7);

        if (aspect_valid) {
            double area = rect.area();
            double aspect_match = 1.0 - fabs(aspect_ratio - 0.583)/0.583;
            double score = area * aspect_match;

            if (score > max_score) {
                max_score = score;
                best_rect = rect;
            }
        }
    }

    if (max_score > 0) {
        cv::rectangle(frame, best_rect, cv::Scalar(0, 255, 255), 2);
        cv::Point center(
            best_rect.x + best_rect.width/2, 
            best_rect.y + best_rect.height/2
        );
        cv::circle(frame, center, 8, cv::Scalar(255, 0, 0), -1);
        m_hasTarget = true;
        m_targetCenter = center;
    } else {
        m_hasTarget = false;
    }
}
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

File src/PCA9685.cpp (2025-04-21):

// PCA9685.cpp
#include "PCA9685.h"

PCA9685::PCA9685() {
    if((i2c_fd = open(I2C_DEV, O_RDWR)) < 0) {
        throw std::runtime_error("Failed to open I2C device");
    }
    if(ioctl(i2c_fd, I2C_SLAVE, PCA9685_ADDR) < 0) {
        close(i2c_fd);
        throw std::runtime_error("Failed to set I2C address");
    }
    reset();
    setPWMFreq(50);
}

PCA9685::~PCA9685() {
    if(i2c_fd >= 0) close(i2c_fd);
}

void PCA9685::writeReg(uint8_t reg, uint8_t value) {
    uint8_t buffer[2] = {reg, value};
    if(write(i2c_fd, buffer, 2) != 2) {
        throw std::runtime_error("I2C write failed");
    }
}

void PCA9685::reset() {
    writeReg(0x00, 0x00);
    usleep(10000);
}

void PCA9685::setPWMFreq(float freq) {
    freq = std::min(1526.0f, std::max(24.0f, freq));
    float prescale_val = 25000000.0 / 4096.0 / freq - 1.0;
    uint8_t prescale = static_cast<uint8_t>(prescale_val + 0.5);

    uint8_t oldmode = 0;
    if(read(i2c_fd, &oldmode, 1) != 1) {
        throw std::runtime_error("I2C read failed");
    }

    writeReg(0x00, (oldmode & 0x7F) | 0x10);
    writeReg(0xFE, prescale);
    writeReg(0x00, oldmode);
    usleep(5000);
    writeReg(0x00, oldmode | 0xA1);
}

void PCA9685::setPWM(uint8_t channel, uint16_t on, uint16_t off) {
    uint8_t reg = 0x06 + 4 * channel;
    uint8_t data[5] = {
        reg,
        static_cast<uint8_t>(on & 0xFF),
        static_cast<uint8_t>(on >> 8),
        static_cast<uint8_t>(off & 0xFF),
        static_cast<uint8_t>(off >> 8)
    };
    if(write(i2c_fd, data, 5) != 5) {
        throw std::runtime_error("PWM set failed");
    }
}

void PCA9685::setAngle(uint8_t channel, float angle) {
    angle = std::min(180.0f, std::max(0.0f, angle));
    const float pulse_us = 500.0f + (angle * 2000.0f) / 180.0f;
    const uint16_t tick = static_cast<uint16_t>((pulse_us * 4096.0f) / 20000.0f);
    setPWM(channel, 0, tick);
}

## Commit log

2025-04-18 Add servo test with PCA9685 driver and documentation
2025-04-18 Integrated live camera feed into Qt UI. Added two bottom buttons (Auto Shoot, Track Shoot) for future GPIO control. UI layout finalized and ready for interaction logic.
2025-04-20 Add GPIO relay switch unit test with README and graceful shutdown logic
2025-04-20 ServoCam Test
2025-04-21 docs: add third‑party libcamera2opencv reference
